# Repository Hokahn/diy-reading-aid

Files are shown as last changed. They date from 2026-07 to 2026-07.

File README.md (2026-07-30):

# Reading Aid (Lesehilfe) for the Visually Impaired

This is a standalone electronic magnifier using a Raspberry Pi 3B and a Raspberry Pi Camera Module 3. It boots directly into a live, magnified camera feed on an external monitor. No login screen, desktop, keyboard, or mouse is required during normal operation. Four large metal buttons control the zoom and brightness/contrast. The reading material is moved by hand under the fixed, downward-facing camera.

grafik

This was built for an elderly relative who is not comfortable with computers. The goal was an appliance that works like a TV: plug in the power, and the image appears.

## Hardware list

| Component | Description |
| --- | --- |
| Raspberry Pi 3 Model B, 1 GB RAM | Main computer |
| Raspberry Pi Camera Module 3 | Fixed, facing straight down |
| Dell 2001fp monitor | 4:3, 1600x1200 native, landscape orientation. Powers the Pi via its built-in USB port. No separate Pi power supply used |
| Micro-USB cable | Power: Dell 2001fp USB port to Pi micro-USB power input |
| DVI-to-HDMI cable | Video: Pi HDMI output to Dell 2001fp DVI input |
| 4x large metal push buttons | Zoom in, zoom out, brightness/contrast up, brightness/contrast down. Large buttons chosen for accessibility |
| Micro-SD card (16 GB+) | Boot / storage |
| 3D printed camera mount and button enclosure | Printed on a Bambu Lab A1, see 3D printed parts |
| Hookup wire | Buttons to GPIO header |

No internet connection is used or required. The device is fully offline.

## 3D printed parts

All enclosure and mount parts were designed with SE Student Edition for and printed on a Bambu Lab A1.

## Wiring and GPIO pinout

All four buttons are wired as simple momentary switches between a GPIO pin and Ground (GND), using the internal pull-up resistors of the Pi handled automatically by gpiozero.Button. No external resistors are needed.

| Function | GPIO (BCM) | Physical pin |
| --- | --- | --- |
| Zoom in | GPIO 17 | 11 |
| Zoom out | GPIO 27 | 13 |
| Brightness/contrast up | GPIO 22 | 15 |
| Brightness/contrast down | GPIO 23 | 16 |
| Ground | Any GND pin | 9 |

Each button: one leg to its GPIO pin, the other leg to any GND pin.

Video: Pi Camera Module 3 to CSI camera port via ribbon cable.

Pi HDMI out to DVI-to-HDMI cable to Dell 2001fp DVI-in.

Power: Dell 2001fp USB port to micro-USB cable to Pi power input.

The Pi receives power only when the monitor is powered. There is no separate power switch for the Pi itself. Every time the monitor is switched off, the Pi loses power immediately without a clean shutdown. See Protect the SD card, this is essential for this setup.

## How it works

The display powers the pi directly, so all can be turned on by the push of the monitor on button.

The camera feed is rendered directly to the screen via the DRM/KMS subsystem of the Linux kernel. No desktop environment or window manager is involved.

The camera reads out its full sensor resolution internally so that the digital zoom keeps as much detail as possible, while the main output stream is scaled down to the native resolution of the display to keep power draw manageable.

Focus is fixed because the camera-to-paper distance never changes. Autofocus is not used because it tends to hunt or lock onto the wrong distance at close range.

The four buttons are read via gpiozero. Holding a button down allows for repeated zoom or brightness steps instead of requiring many individual presses.

The program runs as a systemd service and restarts itself automatically if it crashes.

All 3d Print files are available, additionally there was a aluminum 25x25mm square pipe used.

grafik

## Software setup

### 1. Flash Raspberry Pi OS

Use Raspberry Pi OS Lite (64-bit). This avoids login-screen complexity, boots faster, and has fewer background services.

Download and open Raspberry Pi Imager. Choose OS: Raspberry Pi OS (other) then Raspberry Pi OS Lite (64-bit).

Click the advanced options and set:

Hostname: lesehilfe
Enable SSH
Username and password: lesehilfe
Wi-Fi: optional, only needed temporarily for setup

Write the image, insert the SD card into the Pi, and power it up.

### 2. First boot and update

Log into your Pi via PowerShell:

```bash
ssh lesehilfe@lesehilfe.local

```

After logging in, update using these commands:

```bash
ssh lesehilfe@lesehilfe.local
sudo apt update
sudo apt full-upgrade -y
sudo reboot

```

### 3. Install camera libraries

```bash
sudo apt install -y python3-picamera2 python3-gpiozero --no-install-recommends

```

Verify the camera is detected:

```bash
rpicam-hello --list-cameras

```

Expected output includes the imx708 sensor:

```text
0 : imx708 [4608x2592 10-bit RGGB] (/base/soc/i2c0mux/i2c@1/imx708@1a)

```

Note: older Raspberry Pi OS versions used libcamera-hello instead of rpicam-hello. If rpicam-hello is not found, try libcamera-hello, or install the tools explicitly with sudo apt install -y rpicam-apps.

### 4. Copy the program to the Pi

If you know how to use scp from your computer:

```bash
scp lesehilfe.py lesehilfe@lesehilfe.local:/home/lesehilfe/

```

Alternatively, SSH into the Pi and create the file directly:

```bash
sudo nano /home/lesehilfe/lesehilfe.py

```

Paste the full contents of lesehilfe.py from this repository, save, and exit.

### 5. Set display resolution and focus

Open the file and check these constants match your hardware:

```python
DISPLAY_WIDTH = 1600
DISPLAY_HEIGHT = 1200

```

This MUST match your monitor actual native resolution. To check:

```bash
sudo apt install -y libdrm-tests
modetest -M vc4 -c

```

Look for the connected connector and the mode marked preferred.

Focus is fixed and manual. Measure the real distance between the camera lens and the surface the newspaper lies on, then set the following variable:

```python
FESTER_FOKUS_DIOPTRIEN = 1 / 0.20

```

The 0.20 is the camera-to-paper distance in metres. Fine-tune in small steps after the first test run until text is sharp.

### 6. Manual test run

If the systemd service is already running, stop it first. Only one process can use the camera at a time:

```bash
sudo systemctl stop lesehilfe.service
sudo python3 /home/lesehilfe/lesehilfe.py

```

The camera feed should appear on the monitor. Test all four buttons. Stop with Ctrl+C.

### 7. Disable the login console

Raspberry Pi OS Lite runs a text login prompt on tty1 by default. This holds onto the display output and conflicts with the camera preview. You will see an error like ValueError: drmModeAddFB2 failed: Invalid argument.

Disable it permanently:

```bash
sudo systemctl stop getty@tty1
sudo systemctl disable getty@tty1

```

### 8. Hide the boot screen

This prevents the Pi from showing boot text before the camera feed starts.

```bash
sudo nano /boot/firmware/cmdline.txt

```

Append this to the end of the single line, separated by a space:

```text
quiet splash loglevel=0 logo.nologo vt.global_cursor_default=0 systemd.show_status=0

```

```bash
sudo nano /boot/firmware/config.txt

```

Append at the end:

```text
disable_splash=1

```

### 9. Autostart via systemd

Create the service file on the Pi:

```bash
sudo nano /etc/systemd/system/lesehilfe.service

```

```ini
[Unit]
Description=Lesehilfe Kamera Feed
After=local-fs.target

[Service]
ExecStart=/usr/bin/python3 /home/lesehilfe/lesehilfe.py
Restart=always
RestartSec=2
User=root

[Install]
WantedBy=multi-user.target

```

Save, exit, then:

```bash
sudo systemctl daemon-reload
sudo systemctl enable lesehilfe.service

```

### 10. Reboot test

```bash
sudo reboot

```

After reboot the monitor should show the live camera feed directly. Reconnect via SSH to verify:

```bash
systemctl status lesehilfe.service

```

It should show active (running).

### 11. Power-saving settings

Power comes only from the monitor USB port. Keeping power draw low reduces the risk of under-voltage brownouts, which can cause crashes.

Disable unused hardware by adding to /boot/firmware/config.txt:

```text
dtoverlay=disable-wifi
dtoverlay=disable-bt
dtparam=act_led_trigger=none
dtparam=act_led_activelow=off
dtparam=pwr_led_trigger=none
dtparam=pwr_led_activelow=off

```

Disable unused services:

```bash
sudo systemctl disable bluetooth hciuart wpa_supplicant
sudo systemctl disable triggerhappy
sudo systemctl disable ModemManager

```

Reduce CPU and GPU clock by adding to /boot/firmware/config.txt:

```text
arm_freq=800
core_freq=300
sdram_freq=400
over_voltage=0

```

Use the powersave CPU governor instead of the default ondemand governor:

```bash
echo "powersave" | sudo tee /sys/devices/system/cpu/cpu*/cpufreq/scaling_governor

```

To make this persist across reboots, add it as a systemd service or append it to /etc/rc.local before the exit 0 line.

Check for under-voltage:

```bash
vcgencmd get_throttled
vcgencmd measure_temp

```

0x0 means no under-voltage has occurred since boot. Any other value means the Pi has been under-powered at some point.

### 12. Protect the SD card

The Pi loses power when the monitor is switched off. Repeated hard power-cuts can corrupt the SD card. Enable the overlay filesystem to make the root filesystem effectively read-only.

```bash
sudo raspi-config

```

Navigate to Performance Options or Advanced Options, then Overlay File System, enable it, and confirm the reboot.

While the overlay is active, file changes do not persist. To make changes: disable the overlay, edit, test, and re-enable the overlay.

## Known issues and fixes

| Issue | Fix |
| --- | --- |
| AttributeError: tuple object has no attribute width | Some picamera2 versions return PixelArrayActiveAreas as a plain tuple instead of a Rectangle object. The script handles both cases with a hasattr check. |
| ValueError: drmModeAddFB2 failed: Invalid argument | Caused by getty on tty1 holding the display, or under-voltage on the Pi. |
| Under-voltage detected | Current draw spikes exceed what the monitor USB port can deliver. Mitigate with power-saving settings, a thick USB cable, or reducing camera output resolution. |
| RuntimeError: Failed to acquire camera: Device or resource busy | Happens if you run the script manually while the systemd service is already running. Stop the service before manual testing. |
| Low effective zoom resolution or soft image | Digital zoom crops from an already-reduced image. Fix by requesting an explicit raw stream at the full sensor resolution alongside the smaller main output stream. |
| Autofocus not focusing correctly at close range | Continuous autofocus is unreliable at 10 to 20 cm distances. Switch to manual focus calibrated for the fixed distance. |
| Wrong username in default path | If you chose a different username during imaging, paths like /home/lesehilfe/ must use your actual home directory. |

## Maintenance and making further changes

Because the overlay filesystem is enabled, any file change is temporary until you disable it.

```bash
sudo raspi-config

```

Disable the Overlay File System and reboot.

```bash
nano /home/lesehilfe/lesehilfe.py

```

Make your changes, then restart the service:

```bash
sudo systemctl restart lesehilfe.service
journalctl -u lesehilfe.service -f

```

Re-enable the Overlay File System via raspi-config and reboot.

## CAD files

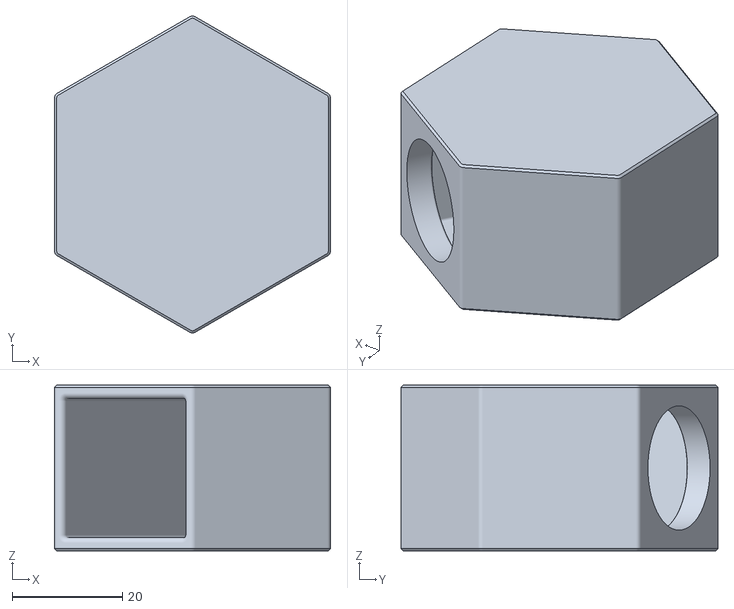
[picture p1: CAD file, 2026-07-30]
3D-Print-STL/Monitorhalter_Alternative.stl
50.0 x 57.4 x 30.0

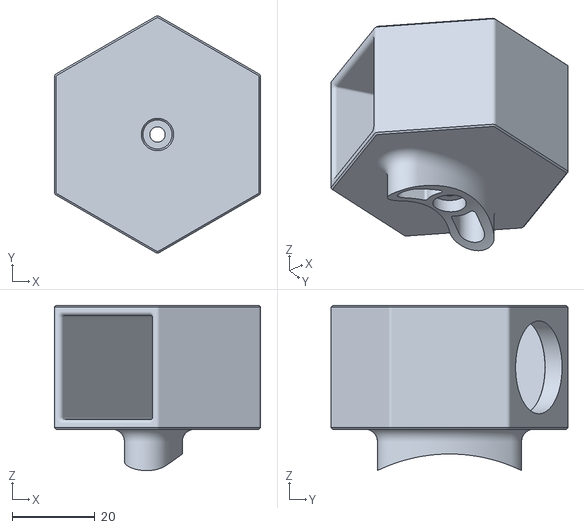
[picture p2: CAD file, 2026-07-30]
3D-Print-STL/02_Monitorhalter.stl
50.0 x 57.4 x 40.0

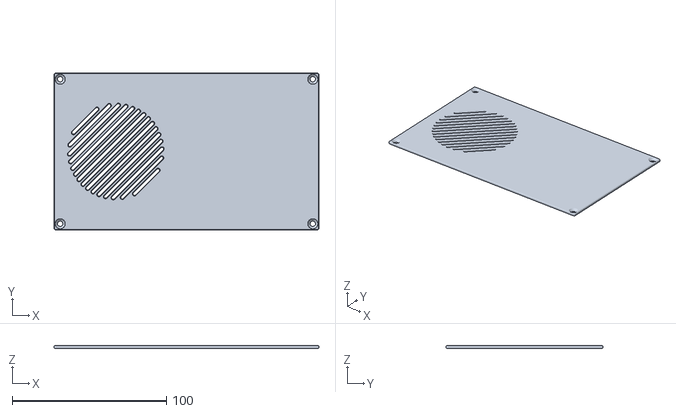
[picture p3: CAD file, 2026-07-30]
3D-Print-STL/03_Abdeckung.stl
171.6 x 101.6 x 2.00

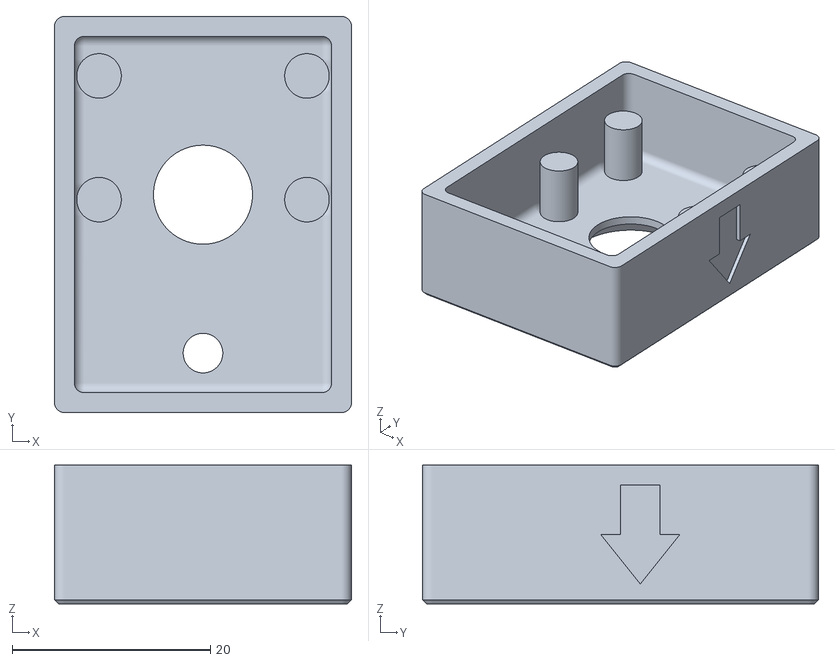
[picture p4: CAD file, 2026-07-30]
3D-Print-STL/04_Kameraschutz.stl
30.0 x 40.0 x 14.0

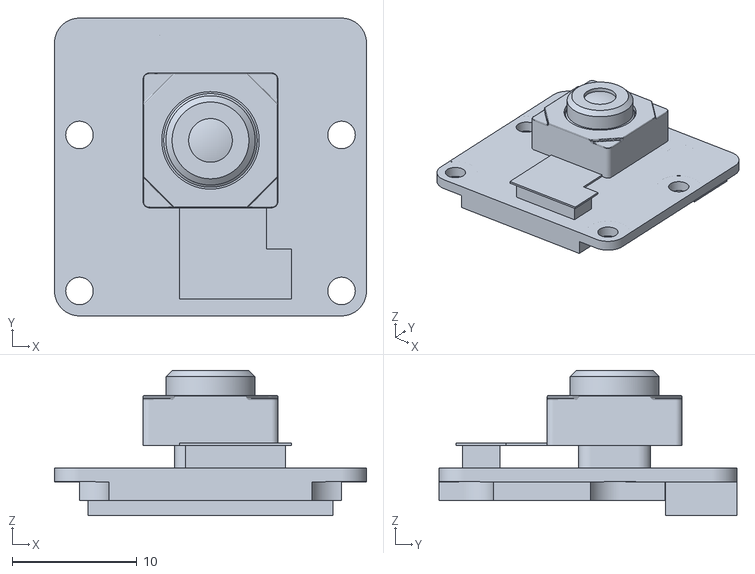
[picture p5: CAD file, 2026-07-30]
3D-Print-STL/06_Raspberry_PI_Cam V2.1.stl
25.0 x 23.9 x 11.6

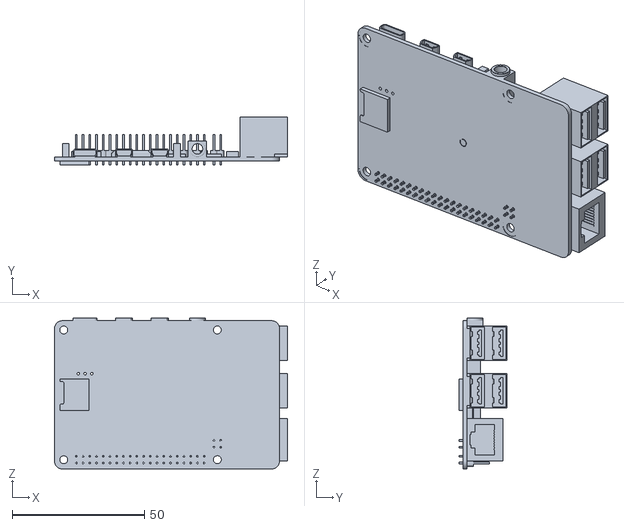
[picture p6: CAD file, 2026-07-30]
3D-Print-STL/05_Raspberry_Pi.stl
88.0 x 18.0 x 57.0

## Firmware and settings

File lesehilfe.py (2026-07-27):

#!/usr/bin/env python3
"""
Lesehilfe für Raspberry Pi 3B + Raspberry Pi Kamera 3
- Startet den Kamerafeed direkt auf dem HDMI-Ausgang (kein Desktop nötig)
- 4 Taster: Zoom rein, Zoom raus, heller/mehr Kontrast, dunkler/weniger Kontrast
- Läuft dauerhaft als systemd-Dienst, startet sich bei Fehlern selbst neu
"""

import logging
import time

from gpiozero import Button
from picamera2 import Picamera2, Preview

# ---------------------------------------------------------------------------
# Konfiguration – hier bei Bedarf anpassen
# ---------------------------------------------------------------------------

# GPIO-Pins der vier Taster (BCM-Nummerierung)
PIN_ZOOM_IN = 17
PIN_ZOOM_OUT = 27
PIN_HELLER = 22
PIN_DUNKLER = 23

# Auflösung des angeschlossenen Displays (Dell 2001fp, natives Querformat 4:3,
# physisch um 90° gedreht montiert -> Kamera ist ebenfalls physisch gedreht,
# daher ist im Bild/Code KEINE Rotation nötig)
DISPLAY_WIDTH = 1600
DISPLAY_HEIGHT = 1200

# Sensor-/Bildauflösung, die von der Kamera aufgenommen wird
CAMERA_WIDTH = 1600
CAMERA_HEIGHT = 1200

# Feste Fokusdistanz (manueller Fokus, da der Abstand Kamera–Zeitung konstant ist)
# LensPosition in Dioptrien = 1 / Abstand_in_Metern.
# Kalibriert für 20 cm Abstand Kamera->Zeitung. Bei anderem Abstand die 0.20 anpassen.
FESTER_FOKUS_DIOPTRIEN = 1 / 0.20

# Zoom-Grenzen und Schrittweite
ZOOM_MIN = 0.15   # kleinster Ausschnitt = stärkster Zoom
ZOOM_MAX = 1.0    # kompletter Sensorbereich = kein Zoom
ZOOM_SCHRITT = 0.05

# Helligkeits-/Kontrast-Grenzen und Schrittweite
HELLIGKEIT_MIN, HELLIGKEIT_MAX = -1.0, 1.0
KONTRAST_MIN, KONTRAST_MAX = 0.0, 2.0
WERT_SCHRITT = 0.05

# Taste gedrückt halten = wiederholtes Auslösen (Komfortfunktion)
HOLD_WIEDERHOLRATE = 0.15  # Sekunden zwischen Wiederholungen beim Gedrückthalten

# ---------------------------------------------------------------------------
# Logging (hilfreich, falls über journalctl Fehler analysiert werden müssen)
# ---------------------------------------------------------------------------
logging.basicConfig(level=logging.INFO, format="%(asctime)s %(levelname)s: %(message)s")
log = logging.getLogger("lesehilfe")

# ---------------------------------------------------------------------------
# Zustand
# ---------------------------------------------------------------------------
zoom_level = 1.0
helligkeit = 0.0
kontrast = 1.0


def kamera_starten() -> Picamera2:
    """Initialisiert die Kamera und startet die Vorschau direkt über DRM/HDMI."""
    picam2 = Picamera2()

    # "raw" erzwingt den vollen Sensor-Auslesebereich (kein Binning), damit beim
    # Zoomen (ScalerCrop) die volle Detailschärfe des Sensors zur Verfügung steht.
    # "main" bleibt bei der kleineren Zielauflösung für Anzeige/Performance/Strom.
    sensor_modes = picam2.sensor_modes
    volle_sensor_groesse = max(sensor_modes, key=lambda m: m["size"][0] * m["size"][1])["size"]

    config = picam2.create_preview_configuration(
        main={"size": (CAMERA_WIDTH, CAMERA_HEIGHT)},
        raw={"size": volle_sensor_groesse},
    )
    picam2.configure(config)

    # DRM-Preview: zeichnet direkt auf den Bildschirm, ganz ohne Desktop/X11/Wayland
    picam2.start_preview(
        Preview.DRM, x=0, y=0, width=DISPLAY_WIDTH, height=DISPLAY_HEIGHT
    )

    picam2.start()

    # Fokus fest einstellen, damit die Kamera nicht ständig nachfokussiert
    picam2.set_controls({"AfMode": 0, "LensPosition": FESTER_FOKUS_DIOPTRIEN})

    return picam2


def update_kamera(picam2: Picamera2) -> None:
    """Sendet aktuelle Helligkeit, Kontrast und Zoom-Ausschnitt an die Kamera."""
    picam2.set_controls({"Brightness": helligkeit, "Contrast": kontrast})

    sensor_box = picam2.camera_properties["PixelArrayActiveAreas"][0]
    # Je nach picamera2-Version ist das entweder ein Rectangle-Objekt
    # (mit .width/.height) oder ein einfaches Tupel (x, y, width, height).
    if hasattr(sensor_box, "width"):
        max_w = sensor_box.width
        max_h = sensor_box.height
    else:
        max_w = sensor_box[2]
        max_h = sensor_box[3]

    neu_w = int(max_w * zoom_level)
    neu_h = int(max_h * zoom_level)
    x = int((max_w - neu_w) / 2)
    y = int((max_h - neu_h) / 2)

    picam2.set_controls({"ScalerCrop": (x, y, neu_w, neu_h)})


def zoom_in(picam2: Picamera2) -> None:
    global zoom_level
    zoom_level = max(ZOOM_MIN, zoom_level - ZOOM_SCHRITT)
    update_kamera(picam2)


def zoom_out(picam2: Picamera2) -> None:
    global zoom_level
    zoom_level = min(ZOOM_MAX, zoom_level + ZOOM_SCHRITT)
    update_kamera(picam2)


def werte_erhoehen(picam2: Picamera2) -> None:
    global helligkeit, kontrast
    helligkeit = min(HELLIGKEIT_MAX, helligkeit + WERT_SCHRITT)
    kontrast = min(KONTRAST_MAX, kontrast + WERT_SCHRITT)
    update_kamera(picam2)


def werte_verringern(picam2: Picamera2) -> None:
    global helligkeit, kontrast
    helligkeit = max(HELLIGKEIT_MIN, helligkeit - WERT_SCHRITT)
    kontrast = max(KONTRAST_MIN, kontrast - WERT_SCHRITT)
    update_kamera(picam2)


def taster_einrichten(picam2: Picamera2) -> None:
    """Verbindet die vier Taster mit den Funktionen. when_held sorgt dafür,
    dass Gedrückthalten wiederholt auslöst statt nur einmal pro Druck."""
    btn_zoom_in = Button(PIN_ZOOM_IN, hold_repeat=True, hold_time=HOLD_WIEDERHOLRATE)
    btn_zoom_out = Button(PIN_ZOOM_OUT, hold_repeat=True, hold_time=HOLD_WIEDERHOLRATE)
    btn_heller = Button(PIN_HELLER, hold_repeat=True, hold_time=HOLD_WIEDERHOLRATE)
    btn_dunkler = Button(PIN_DUNKLER, hold_repeat=True, hold_time=HOLD_WIEDERHOLRATE)

    btn_zoom_in.when_pressed = lambda: zoom_in(picam2)
    btn_zoom_in.when_held = lambda: zoom_in(picam2)

    btn_zoom_out.when_pressed = lambda: zoom_out(picam2)
    btn_zoom_out.when_held = lambda: zoom_out(picam2)

    btn_heller.when_pressed = lambda: werte_erhoehen(picam2)
    btn_heller.when_held = lambda: werte_erhoehen(picam2)

    btn_dunkler.when_pressed = lambda: werte_verringern(picam2)
    btn_dunkler.when_held = lambda: werte_verringern(picam2)

    # Referenzen zurückgeben, damit sie nicht vom Garbage Collector entfernt werden
    return btn_zoom_in, btn_zoom_out, btn_heller, btn_dunkler


def main() -> None:
    log.info("Starte Lesehilfe...")
    picam2 = kamera_starten()
    update_kamera(picam2)  # Startwerte einmal anwenden

    tasten = taster_einrichten(picam2)  # noqa: F841 (Referenzen halten)
    log.info("Lesehilfe läuft. Warte auf Tastendrücke...")

    while True:
        time.sleep(1)


if __name__ == "__main__":
    try:
        main()
    except Exception:
        log.exception("Unerwarteter Fehler - Dienst wird von systemd neu gestartet.")
        raise
